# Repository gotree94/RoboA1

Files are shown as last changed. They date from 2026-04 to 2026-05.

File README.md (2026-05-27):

# RoboA1
RoboA1

https://howtomechatronics.com/how-it-works/harmonic-vs-cycloidal-drive-designing-3d-printing-testing/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

---

# Harmonic vs Cycloidal Drive – 토크, 백래시 및 마모 테스트

이 글에서는 3D 프린팅된 조화 드라이브와 3D 프린팅된 사이클로이드 드라이브 중 어느 쪽이 더 나은지 살펴보겠습니다. 여기 제가 만든 두 개의 기어박스가 있는데, 크기와 감량 비율이 25:1입니다. 여러 카테고리에서 비교하고, 효율이나 토크 출력을 측정하며, 정확도나 백래시도 측정하고, 내구성을 확인할 것입니다.

Harmonic vs Cycloidal

## 목차

1. [동작 원리 개요](#동작-원리-개요)
2. [설계](#설계)
   - [사이클로이드 드라이브 설계](#사이클로이드-드라이브-설계)
   - [고조파 구동 설계](#고조파-구동-설계)
3. [3D 모델 및 STL 파일 다운로드](#3d-모델-및-stl-파일-다운로드)
4. [3D 프린팅](#3d-프린팅)
5. [조립](#조립)
   - [사이클로이드 구동 조립체](#사이클로이드-구동-조립체)
   - [하모닉 드라이브 어셈블리](#하모닉-드라이브-어셈블리)
6. [문제 해결](#문제-해결)
7. [하모닉 vs 사이클로이드 – 비교](#하모닉-vs-사이클로이드--비교)
   - [백래시](#백래시)
   - [토크](#토크)
8. [결론](#결론)

---

## 동작 원리 개요

이미 제 채널에 고조파 구동과 사이클로이드 구동이 무엇이고 어떻게 작동하는지, 그리고 설계 방법을 자세히 설명하는 전용 영상이 있으니, 더 자세한 내용은 그 튜토리얼들을 확인해 보시길 권합니다.

간단히 말해, 하모닉 드라이브와 사이클로이드 드라이브 모두 독특한 유형의 기어박스 또는 감속기로, 매우 높은 감속비를 제공하면서도 컴팩트하면서도 견고한 설계를 제공합니다. 작동 원리는 비슷한데, 입력축이 비규칙 모양 부품을 구동하고, 조화 구동 방식은 파동 발생기, 사이클로이드 구동 방식은 이심 베어링을 구동합니다.

각 기어박스가 가진 독특한 부품들의 도움으로 매우 작은 공간에서 훨씬 낮은 속도로 출력을 낼 수 있습니다.

### 감축비

- **고조파 구동**의 감축비는 항상 플렉스 스플라인 이빨 수의 절반입니다. 25:1 감축비를 원한다면, 플렉스 스플라인에는 50개의 이빨, 원형 스플라인에는 52개의 이빨이 필요합니다.
- **사이클로이드 구동**의 감축 비율은 항상 링 기어의 핀 수보다 1개 적으며, 25:1 감축 비율을 위해서는 링 기어에 26개의 핀이 필요합니다.

---

## 설계

두 기어박스를 같은 크기와 감축 비율(25:1)로 만들어서 쉽게 비교할 수 있게 하는 것이 목표였습니다. 기어박스를 최대한 작게 만들고 싶었습니다.

### 사이클로이드 드라이브 설계

첫 입력 매개변수는 사이클로이드 구동 링 기어용 롤러에 장착된 핀 크기였습니다. 6mm 핀을 가지고 있었는데, 더 부드러운 작동을 위해 8mm 부싱에 장착할 계획이었습니다. 8mm 직경의 26개 롤러와 부싱으로 스케치를 그렸습니다.

이 두 입력 매개변수에 따라 링 기어 피치 직경의 최소 크기를 정의할 수 있으며, 이는 결국 기어박스 크기를 결정합니다. 하우징 직경은 26개 부싱 전부를 모두 수용하고 전체 기어박스를 조립할 수 있는 M4 볼트를 넣을 수 있는 벽 두께를 확보하기 위해 95mm여야 했습니다.

사이클로이드 디스크 형태를 생성하려면 한 가지 추가 입력 매개변수가 필요한데, 바로 **이심도 값(Eccentricity)**으로, 핀 직경의 절반보다 작아야 합니다.

#### 사이클로이드 디스크 매개변수 방정식 (Omar Younis)

```
N  - Number of rollers
Rr - Radius of the roller
R  - Radius of the rollers PCD (Pitch Circle Diameter)
E  - Eccentricity - offset from input shaft to a cycloidal disk

x = (R*cos(t)) - (Rr*cos(t + arctan(sin((1-N)t) / (R/(E*N) - cos((1-N)t))))) - (E*cos(N*t))
y = (-R*sin(t)) + (Rr*sin(t + arctan(sin((1-N)t) / (R/(E*N) - cos((1-N)t))))) + (E*sin(N*t))
```

**적용 예 (25:1, N=26):**

| 파라미터 | 값  |
|---|-----|
| N | 26  |
| Rr | 3 |
| R | 36  |
| E | 0.75 |

```
x = (36*cos(t)) - (3*cos(t + arctan(sin((1-26)t) / (36/(0.75*26) - cos((1-26)t))))) - (0.75*cos(26*t))
y = (-36*sin(t)) + (3*sin(t + arctan(sin((1-26)t) / (36/(0.75*26) - cos((1-26)t))))) + (0.75*sin(26*t))
```

> "t" 파라미터는 0부터 2π까지의 값을 사용해야 합니다. 다만, 곡선을 생성하려면 2π보다 약간 작은 값을 사용해야 한다는 점을 유의해야 합니다. 이렇게 하면 약간의 간격이 있는 곡선이 생성되고, 스플라인으로 쉽게 연결할 수 있습니다.

프로파일을 압출하고, 이심 베어링과 출력 핀을 위한 구멍을 만들 수 있습니다. 출력 구멍들의 직경은 `핀 롤러 직경 + 편심도의 2배`와 같습니다. 이 경우 `8 + 0.75*2 = 9.5mm` 직경입니다.

### 고조파 구동 설계

두 기어박스 모두 같은 크기로 만드는 것이 아이디어였고, 기어박스 직경은 맞출 수 있었지만 플렉스 스플라인을 수용하기 위해 길이가 조금 더 길어져야 했습니다.

플렉스 스플라인은 매우 독특한 부품으로, 열린 쪽은 유연해야 하지만 하단이나 출력은 강해야 합니다. 사이클로이드 기어박스의 길이 치수에 맞추기 위해 컵을 짧게 만들려 하면, PLA 소재를 사용하고 있어 유연성이 부족하고 벽이 쉽게 부서질 수 있기 때문에 제대로 작동하지 않습니다.

**플렉스 스플라인 설계:**
- SOLIDWORKS 툴박스 사용, 1.5 모듈
- 50개 이빨 스퍼 기어 생성
- 컵 벽: 1.25mm, 컵 전체 길이: 30mm

**원형 스플라인 설계:**
- SOLIDWORKS 툴박스 사용
- 52개 이빨 내부 스퍼 기어
- 기어 내부에 0.1mm 간격 (3D 프린팅 부품 공차 고려)

**파동 발생기:**
- 플렉스 스플라인 내벽 직경보다 장축이 3.2mm 크고, 단축이 3.2mm 작은 타원
- 장축 양쪽에 베어링 3개 배치

---

## 3D 모델 및 STL 파일 다운로드

> 아래에서 고조파 및 사이클로이드 드라이브의 3D 모델과 제조에 필요한 STL 파일을 다운로드할 수 있습니다.

- **하모닉 드라이브 R25 - SOLIDWORKS 파일**
- **사이클로이드 드라이브 R25 - SOLIDWORKS 파일**
- **하모닉 드라이브 STL 파일**
- **사이클로이달 드라이브 STL 파일**

---

## 3D 프린팅

부품의 정확한 치수를 얻기 위해서는 슬라이싱 소프트웨어에 적절한 설정이 필요합니다.

**중요 설정:**
- **수평 확장 (Horizontal Expansion):** 0.02mm
- **구멍 수평 확장 (Hole Horizontal Expansion):** 0.04mm

3D 프린터에서 어떤 값이 가장 좋은 결과를 낼지 테스트 출력을 해보는 것이 좋습니다.

**특수 설정:**
- 플렉스 스플라인과 사이클로이드 디스크: 수평 확장 `–0.01 ~ –0.02mm`
  - 이 부품들은 움직일 수 있도록 클리어런스 핏이 있어야 합니다.

---

## 조립

### 사이클로이드 구동 조립체

**필요 부품 목록:**

| 부품 | 사양 | 수량 |
|---|---|:----:|
| 6mm 강철 실린더 로드 | L=30mm | 26 |
| 6mm 강철 실린더 로드 | L=22mm | 6 |
| 8mm 부싱 | L=20mm | 26 |
| 8mm 부싱 | L=15mm | 6 |
| 볼 베어링 6807 | 35×47×7mm | 2 |
| 볼 베어링 6803 | 17×26×5mm | 2 |
| 볼 베어링 6802 | 15×24×5mm | 2 |
| 나사산 인서트 | M4×5mm | - |
| M3 볼트 | 8mm(8개), 25mm(3개) | - |
| M4 볼트 | 10mm(4개), 35mm(6개) | - |

**조립 시 중요 사항:**
- 두 개의 사이클로이드 디스크를 **180도 위상 차이**로 배치
- 디스크에 뚫린 작은 구멍을 기준으로 정렬

### 하모닉 드라이브 어셈블리

**필요 부품 목록:**

| 부품 | 사양 | 수량 |
|---|---|:----:|
| 볼 베어링 6807 | 35×47×7mm | 1 |
| 볼 베어링 6802 | 15×24×5mm | 1 |
| 볼 베어링 6801 | 12×21×5mm | 1 |
| 나사산 인서트 | M4×5mm | - |
| M3, M4 볼트와 너트 | - | - |

**조립 순서:**
1. 출력 축을 플렉스 스플라인에 고정
2. 플렉스 스플라인을 원형 스플라인에 삽입
3. 파동 발생기(2개 섹션)를 4개의 M3 볼트로 결합
4. 파동 발생기 베어링(내경 6mm, 외경 13mm) 장착
5. 파동 발생기를 플렉스 스플라인에 삽입
6. 원형 스플라인에 전체 어셈블리 삽입
7. 윤활제 도포
8. 하우징 뒷면 뚜껑을 6개의 M4 볼트로 고정
9. 입력축 커플러(NEMA 17 스테퍼 모터용) 연결
10. 장착 브래킷으로 모터 고정

---

## 문제 해결

사이클로이드 디스크와 비교했을 때, 고조파 구동장치의 움직임이 그리 부드럽지 않았습니다. 원인은 다음과 같습니다:

### 1. 플렉스 스플라인 파손
- 컵 벽이 너무 얇아 변형을 견디지 못함
- 컵이 너무 작아 탄성 변형 수용이 어려움
- 다른 필라멘트 + 벽 두께 3겹 시도했으나 실패

### 2. 파동 발생기 접촉 불량
- 상단 베어링이 플렉스 스플라인에 닿지 않음
- → 파동 발생기를 단일 베어링으로 수정하여 개선

### 3. 내부 표면 불균일
- 3D 프린팅 시 벽선이 하나만 있어 표면이 거침
- → 벽 두께 4겹(1.6mm)으로 증가시켜 표면 개선

### 4. Z 이음매(Z-Seam) 문제
- "사용자 지정" 정렬로 인해 돌출부 발생
- → "랜덤"으로 설정하여 표면과 움직임 개선

---

## 하모닉 vs 사이클로이드 – 비교

### 백래시

| 항목 | 하모닉 드라이브 | 사이클로이드 드라이브 |
|---|:---:|:---:|
| 반복성 | 우수 | 우수 |
| 양방향 힘 (15cm 거리) | 8mm 백래시 | 6.5mm 백래시 |
| 정지 상태 작은 힘 | 우수 (역류 없음) | 약 2mm 유격 |
| 정지 상태 큰 힘 | 최대 7mm 유격 | 약 5.5mm 유격 |

### 토크

| 테스트 | 하모닉 드라이브 | 사이클로이드 드라이브 |
|---|:---:|:---:|
| NEMA17 최대 토크 | 4.8Nm (32N @ 15cm) | 4.8Nm (32N @ 15cm) |
| 효율 | ~65% | ~65% |
| NEMA23 최대 토크 | 즉시 고장 | 21.5Nm (43N @ 0.5m) |
| 토크 증가율 | - | 7배 (3Nm → 21.5Nm) |

사이클로이드 드라이브는 16배 토크 증가 (0.3Nm → 4.8Nm, 효율 65%).

NEMA23 테스트:
- 사이클로이드: 15cm 막대 80N(12Nm)에서 파손 → 합판 막대로 교체 후 0.5m @ 30N(15Nm)에서 디스크 파손 시작 → 보강 후 0.5m @ 43N(21.5Nm)까지 도달
- 하모닉: NEMA23 부하에서 즉시 고장

### 내구성

사이클로이달 구동은 고조파 구동보다 훨씬 더 오래 지속될 수 있습니다. PLA 플렉스 스플라인은 밤새 한 자세로 놓여 있어도 소성 변형이 생길 정도로 내구성이 취약합니다.

---

## 결론

**3D 프린팅된 하모닉 드라이브 vs 3D 프린팅된 사이클로이드 드라이브 – 어느 쪽이 더 나은가?**

정답은 **"상황에 따라 다릅니다."**

### 사이클로이드 드라이브의 장점
- 더 큰 토크 제공
- 더 신뢰할 수 있으며 내구성 우수
- 디스크 정밀도 개선을 통한 백래시 개선 여지 있음

### 하모닉 드라이브의 장점
- 백래시 측면에서 확실히 더 나을 수 있음
- NEMA17 부하에서는 사이클로이드와 유사한 성능

### 한계점
- **하모닉 드라이브:** 플렉스 스플라인의 내구성 문제. 개선하려면 설계가 더 크고 길어져야 하며, 이는 컴팩트함을 희생해야 함.
- **사이클로이드 드라이브:** 고하중에서 디스크 변형 및 파손 가능성

> PLA 이외의 다른 3D 프린팅 재료를 사용하면 두 드라이브 모두 성능이 개선될 수 있습니다.

---

*참고: 이 글은 YouTube 영상 "Harmonic vs Cycloidal Drive – 토크, 백래시 및 마모 테스트"를 기반으로 작성되었습니다.*

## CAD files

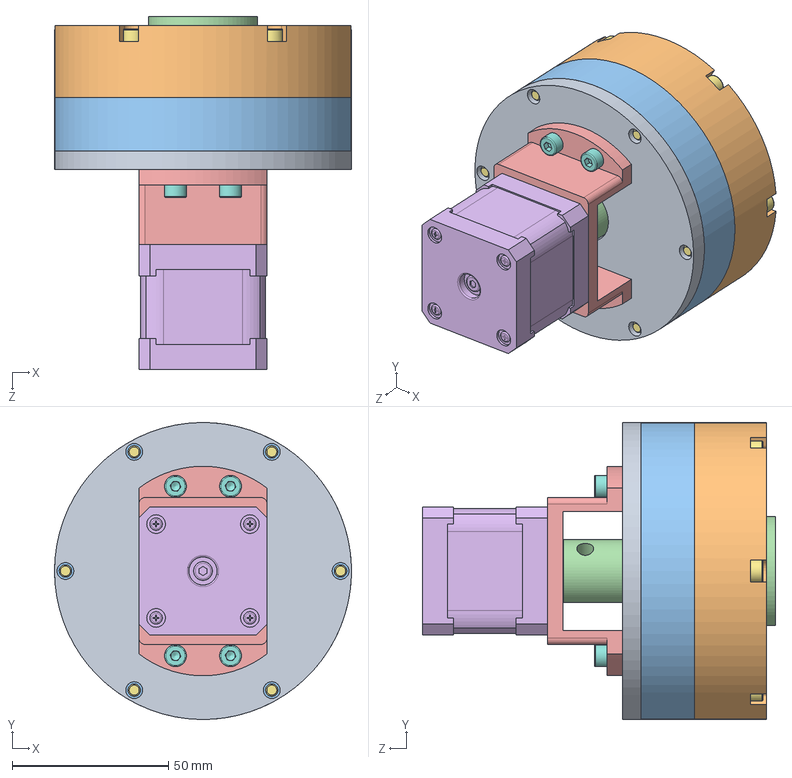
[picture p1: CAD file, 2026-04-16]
ME/Harmonic Drive R-25 - SOLIDWORKS files/Harmonic Drive v3.SLDASM
95.0 x 95.0 x 113.0 mm
Housing - harmonic driver1
Circular spline - module 1point5 - 52 teethr1
Output shaft - harmonic v3r1
Ball Bearing-35x47x7mm h2r1
Ball Bearing-12x21x5mm h1r1
Threaded insert 4x6x5r1
Wave generator v3r1
Housing bottomr1
Wave generator - support shaftr1
Ball Bearing-15x24x5mm h1r1
Input shaft for harmonic drive v3 - for NEMA 23r1
NEMA 17 motor mount h2r1
Stepper NEMA 17 - 20mm shaft r2r1
DIN 912 M4 x 40 --- 20N x 8
6mm shaft - 6mm holer1
Ball Bearing- 6x13x5mm h1r1 x 6
DIN 988-4x8x0.1 x 6
DIN 7991 - M3 x 20 --- 16.8N x 6
DIN EN ISO 7040 - M3 - N x 6
Threaded insert M3 h3r1
DIN 912 M3 x 10 --- 10N x 4
DIN 912 M4 x 10 --- 10N x 6
DIN 912 M4 x 8 --- 8N x 4

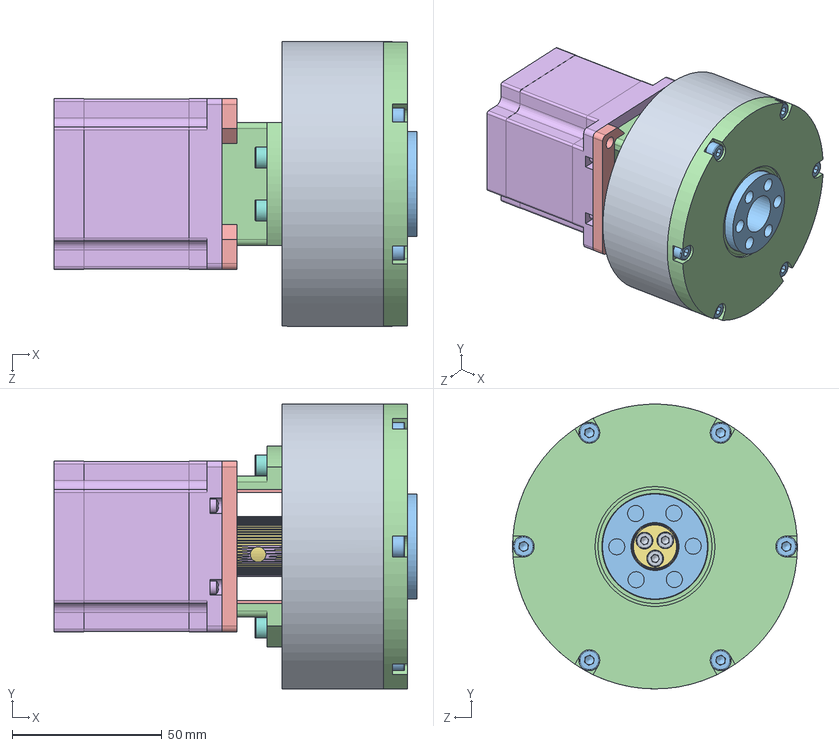
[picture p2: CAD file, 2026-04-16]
ME/Cycloidal Drive R25 - SOLIDWORKS files/Cycloidal Drive v3.SLDASM
121.1 x 95.0 x 95.0 mm
Base housing
Bushing 6x8mm x 58
Pin 6x30mm r1 x 26
Housing lid
Distance ring for rollers bushings
Cycloidal Disk v3 - x 2
Eccentric shaft v3
Ball Bearing-17x26x5mm x 2
Distance ring 2 x 2
Ball Bearing-15x24x5mm 1 x 2
Output shaft v3
Ball Bearing-35x47x7mm 2 x 2
Output shaft p1 v3
Input shaft 1 v3
Stepper NEMA 17 - 20mm shaft r2
Threaded insert M3 v3 x 3
DIN 912 M3 x 25 --- 18N x 3
Pin 6x22mm r1 x 6
DIN 912 M4 x 35 --- 20N x 6
NEMA 17 motor mount r2
DIN 912 M4 x 8 --- 8N x 4

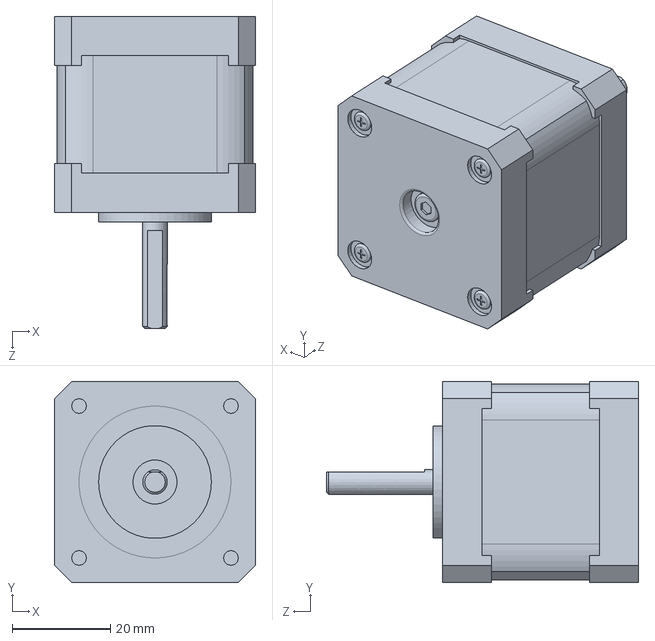
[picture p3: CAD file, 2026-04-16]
ME/Cycloidal Drive R25 - SOLIDWORKS files/Stepper NEMA 17 - 20mm shaft r2.SLDPRT
41.0 x 41.0 x 63.7 mm

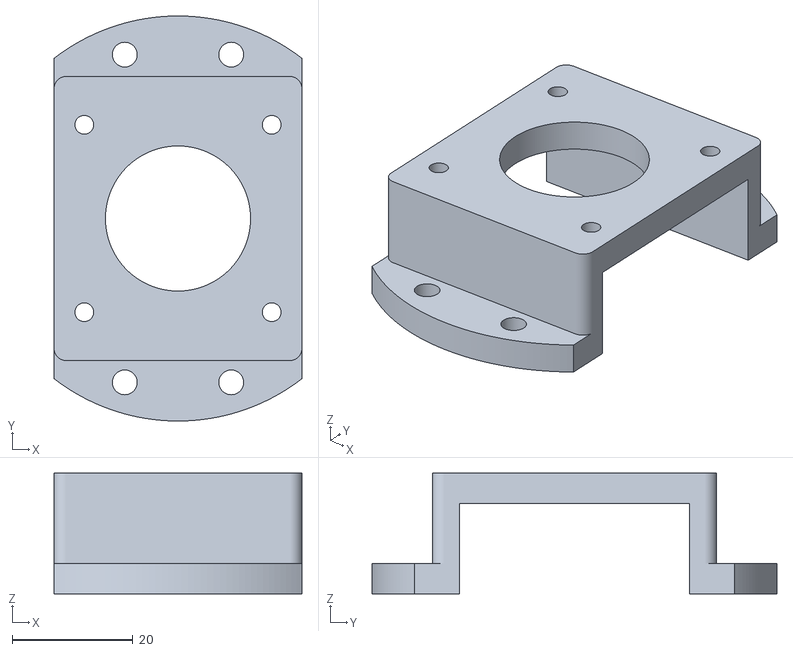
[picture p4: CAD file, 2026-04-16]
ME/Cycloidal Drive STL files/NEMA 17 motor mount r2.STL
41.0 x 67.0 x 20.0

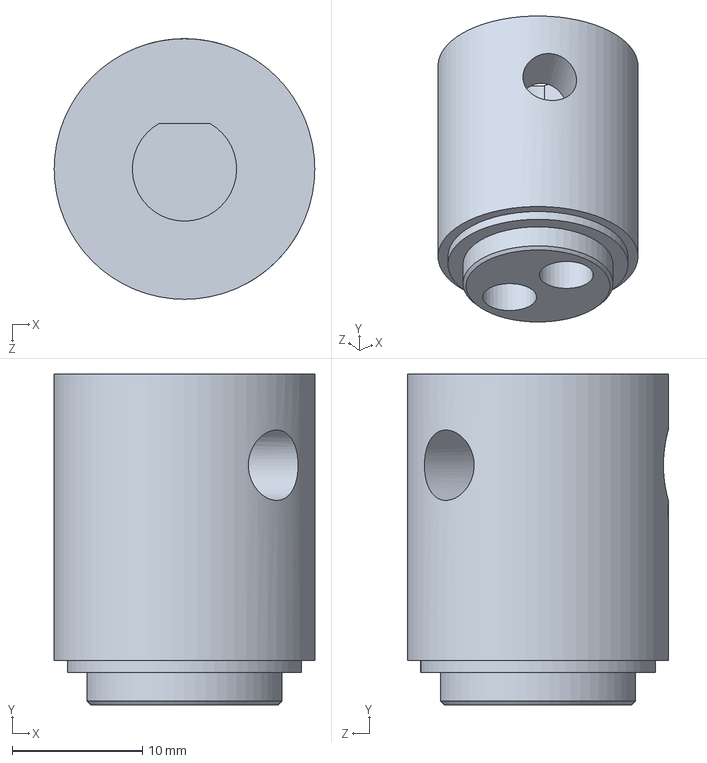
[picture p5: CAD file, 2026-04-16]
ME/Harmonic Drive R-25 - SOLIDWORKS files/Input shaft for harmonic drive v3 - for NEMA 23r1.SLDPRT
20.0 x 25.4 x 20.0 mm

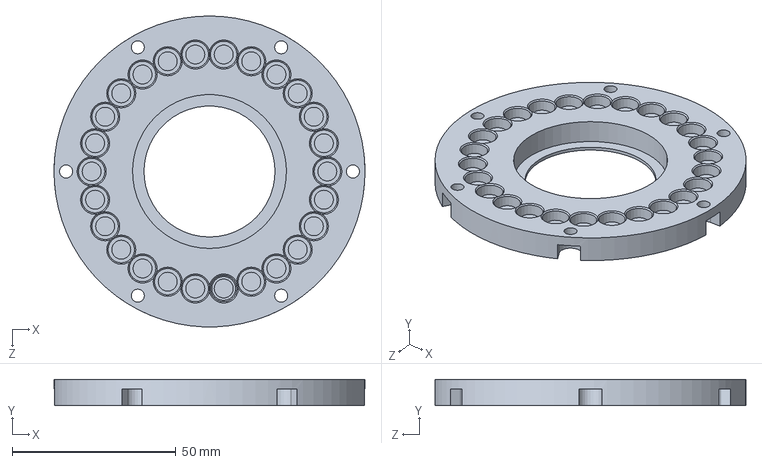
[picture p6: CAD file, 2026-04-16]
ME/Cycloidal Drive R25 - SOLIDWORKS files/Housing lid.SLDPRT
95.0 x 8.00 x 95.0 mm

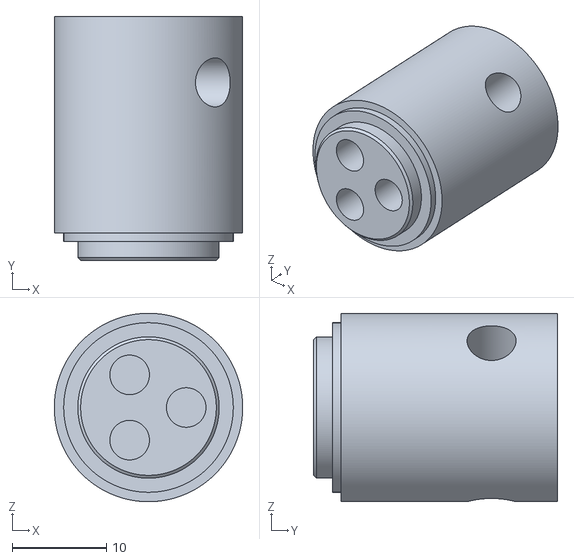
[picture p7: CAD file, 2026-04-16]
ME/Cycloidal Drive STL files/Input shaft 1 v3 - for NEMA 23.STL
20.0 x 25.9 x 20.0

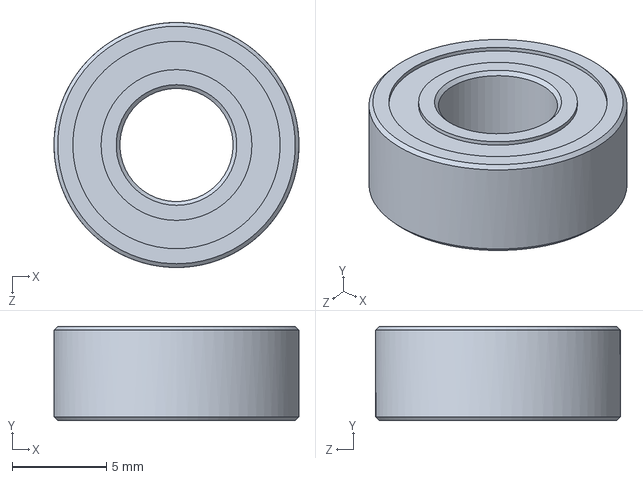
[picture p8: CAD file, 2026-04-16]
ME/Harmonic Drive R-25 - SOLIDWORKS files/Ball Bearing- 6x13x5mm h1r1.SLDPRT
13.0 x 5.00 x 13.0 mm

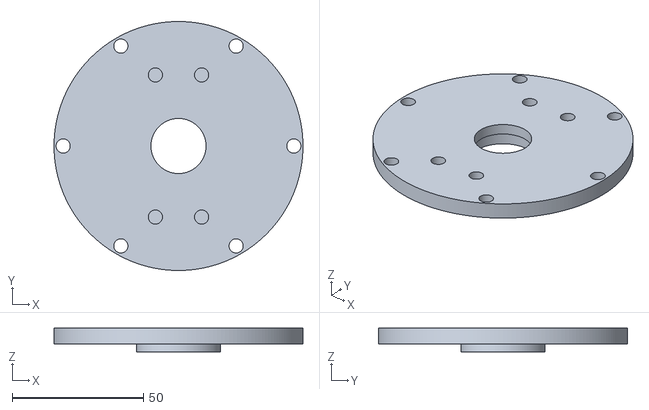
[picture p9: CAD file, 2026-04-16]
ME/Harmonic Drive STL files/Housing bottom.STL
95.0 x 95.0 x 9.00

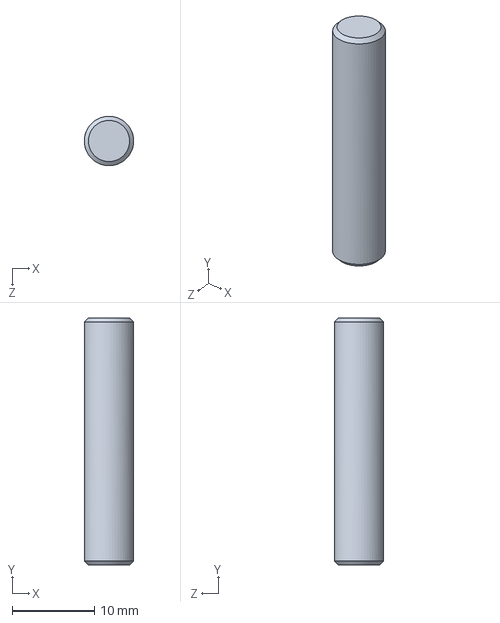
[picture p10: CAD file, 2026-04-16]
ME/Cycloidal Drive R25 - SOLIDWORKS files/Pin 6x30mm r1.SLDPRT
6.00 x 30.0 x 6.00 mm

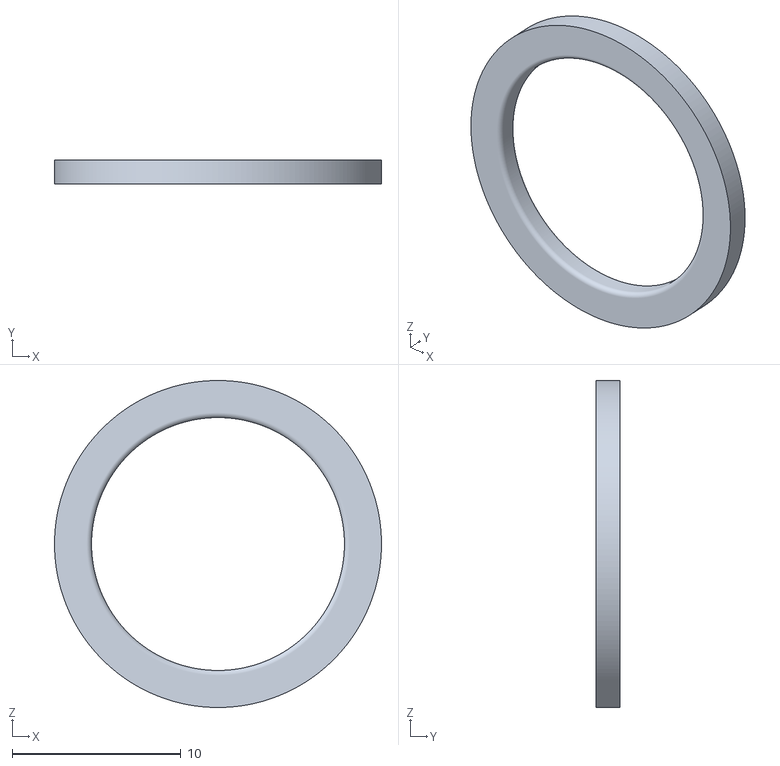
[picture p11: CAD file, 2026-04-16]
ME/Cycloidal Drive STL files/Distance ring 2.STL
19.4 x 1.40 x 19.4

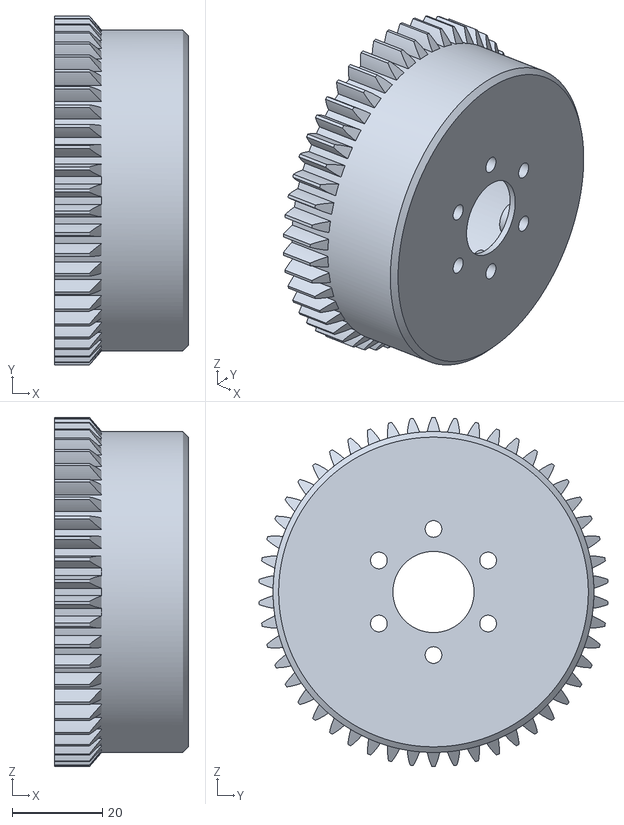
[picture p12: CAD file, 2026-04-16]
ME/Harmonic Drive STL files/Flex spline - m 1point5 - 50 teeth v12 - with more offset on the teeth profile.STL
29.8 x 77.5 x 77.6

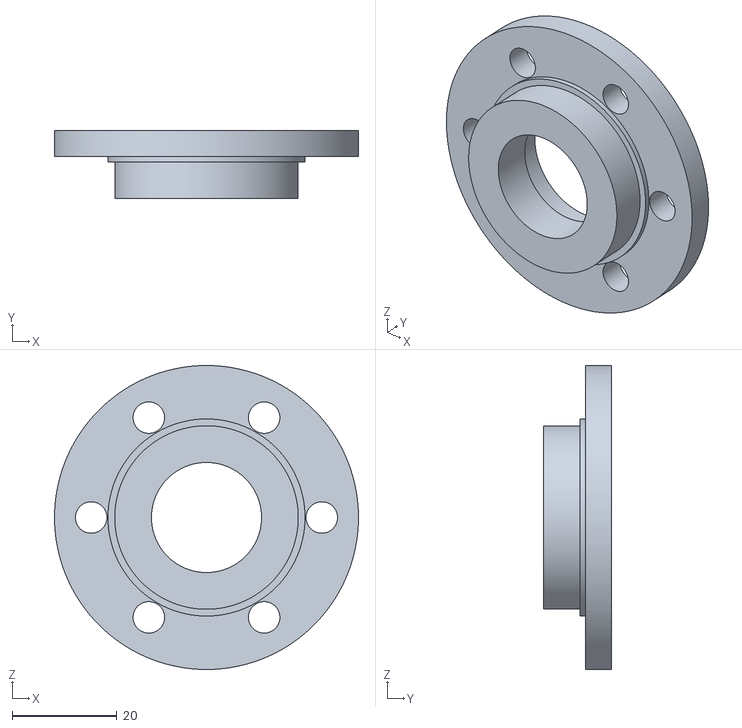
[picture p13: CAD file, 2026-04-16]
ME/Cycloidal Drive STL files/Output shaft p1 v6.STL
58.0 x 13.0 x 58.0

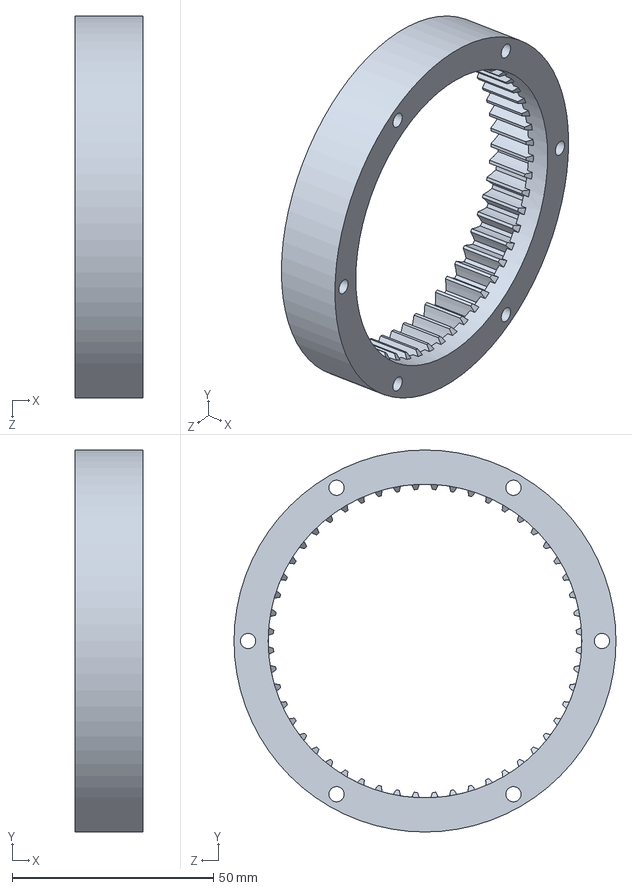
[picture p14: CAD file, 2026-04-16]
ME/Harmonic Drive R-25 - SOLIDWORKS files/Circular spline - module 1point5 - 52 teethr1.SLDPRT
17.0 x 95.0 x 95.0 mm

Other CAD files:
ME/Cycloidal Drive R25 - SOLIDWORKS files/Input shaft 1 v3 - for NEMA 23.SLDPRT
ME/Harmonic Drive STL files/NEMA 23 motor mount h2.STL
ME/Cycloidal Drive R25 - SOLIDWORKS files/Ball Bearing-35x47x7mm 2.SLDPRT
ME/Cycloidal Drive STL files/Housing lid.STL
ME/Cycloidal Drive R25 - SOLIDWORKS files/Ball Bearing-15x24x5mm 1.SLDPRT
ME/Cycloidal Drive R25 - SOLIDWORKS files/Ball Bearing-17x26x5mm.SLDPRT
ME/Cycloidal Drive R25 - SOLIDWORKS files/Base housing.SLDPRT
ME/Cycloidal Drive R25 - SOLIDWORKS files/Bushing 6x8mm.SLDPRT
ME/Cycloidal Drive R25 - SOLIDWORKS files/Cycloidal Disk v3 -.SLDPRT
ME/Cycloidal Drive R25 - SOLIDWORKS files/Distance ring 2.SLDPRT
ME/Cycloidal Drive R25 - SOLIDWORKS files/Distance ring for rollers bushings.SLDPRT
ME/Cycloidal Drive R25 - SOLIDWORKS files/Eccentric shaft v3.SLDPRT
ME/Cycloidal Drive R25 - SOLIDWORKS files/Input shaft 1 v3.SLDPRT
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
